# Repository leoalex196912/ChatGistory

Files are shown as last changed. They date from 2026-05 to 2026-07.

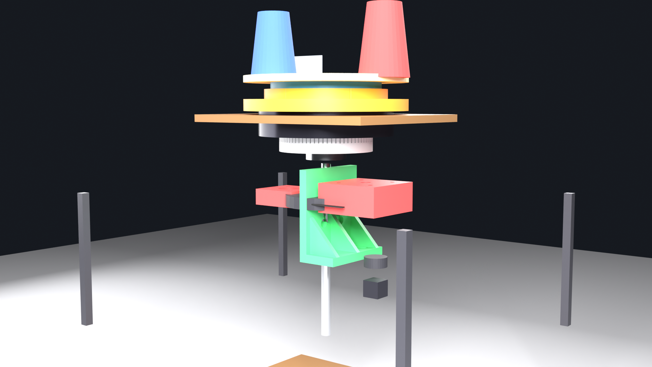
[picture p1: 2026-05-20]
3D-Project/00_PROJECT_OVERVIEW/renders/CSM_V3_Assembly_Hero.png

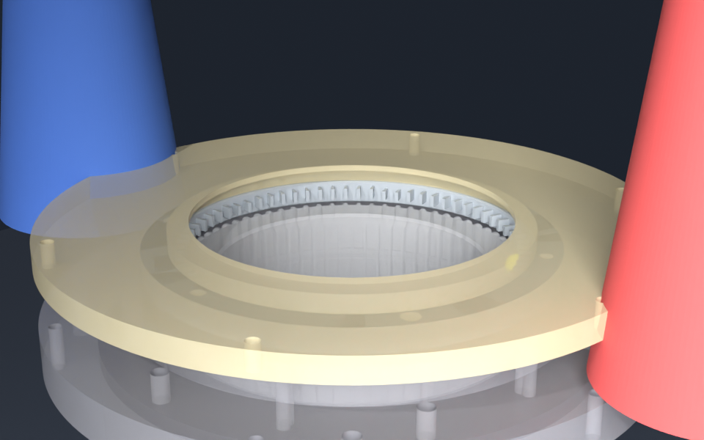
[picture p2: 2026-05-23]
CSM_V3_ASSEMBLY/full_assembly/renders/anim_nominal/frame_0004.png

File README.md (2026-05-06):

<<<<<<< HEAD
# CSM V3 - Computerized Sock Machine V3

Automated Legare-compatible circular sock knitting machine with motorized drive system and computer control.

## Project Status

| Component | Version | Status |
|---|---|---|
| Bearing Housings | V2.5.1 | ✅ Done |
| Drive Hub | V1.3 | ✅ Done |
| Motor Mount | V1.3 | ✅ Done |
| Spacer Tubes | V2.5.1 | ✅ Done |
| Cylinder | V1.1.1 | ✅ Done |
| Cam Ring | V6.5 FINAL | ✅ Done |
| Sinker Ring | V1.2.1 | ✅ Production-ready |
| Retainer Ring | V1.0 | NEXT |
| Cassette Base | V1.0 | After retainer |
| Feeder Module | V1.0 | After cassette |

## Latest: Sinker Ring V1.2.1

- 72 sinker projections with 10° backward angled tips
- Dual clearance test slices (ID 115.3mm and 115.1mm)
- 4 engineering review fixes applied
- ✅ Test slice printed successfully
- ✅ Angled tip geometry validated

## Directory Structure

- `chat-history/` - Full design conversation transcripts
- `freecad-macros/sinker-ring/` - FreeCAD macro (V1.2.1)
- `test-results/` - Print validation testing guide
- `documentation/` - Design specifications

## Next Steps

1. Validate test slice fit on cylinder
2. Print full sinker ring
3. Design Retainer Ring V1.0
4. Design Cassette Base V1.0

## Chat History

All design evolution documented chronologically in chat-history/.

See journal.txt for index.
=======
# ChatGistory
>>>>>>> 52dd906ae06a8ef9a5bce6f71aa1d95e0d1a725d

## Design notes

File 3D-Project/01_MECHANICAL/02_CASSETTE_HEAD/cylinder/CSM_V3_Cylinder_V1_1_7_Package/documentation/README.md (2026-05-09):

# CSM V3 Cylinder V1.1.7

## Status: PRODUCTION-READY (engineering review fixes applied)

## Project Location
`C:\3D-Project\01_MECHANICAL\02_CASSETTE_HEAD\cylinder\`

## Files In This Package

```
CSM_V3_Cylinder_V1_1_7_Package/
├── freecad_macros/
│   ├── CSM_V3_Cylinder_V1_1_7.FCMacro        (production - generates STL)
│   └── CSM_V3_Cylinder_V1_1_7_VIZ.FCMacro    (visualization with needles+spring)
├── blueprints/
│   └── Cylinder_V1_1_7_Blueprint.svg          (ready-to-view standalone SVG)
├── images/
│   (PNGs generated when you RUN the macro on Windows FreeCAD)
├── STL_outputs/
│   (STLs generated when you RUN the macro on Windows FreeCAD)
└── documentation/
    ├── README.md                              (this file)
    ├── VERSION_HISTORY.md
    └── CHAT_HISTORY_LATEST.txt
```

## Critical Specifications

| Parameter | Value | Notes |
|---|---|---|
| Cylinder OD | 114.3mm | Legare 4.5" standard |
| Cylinder ID | 88.0mm | Bore for drive hub |
| Height | 75.0mm | Total axial length |
| Slot count | 72 | Standard adult sock |
| Slot W × D | 1.22 × 2.00mm | For 12g needle ribbon |
| Slot length | 52.0mm | Stem zone |
| Slot chamfer | 0.8mm | Lead-in at top (V1.1.3 fix) |
| Butt cavity | 8.5 × 4.0mm | At Z=19-23mm (cam zone) |
| Spring groove Z | 60.4-63.6mm | Center Z=62mm (V1.1.7 fix) |
| Spring groove depth | 1.8mm | Less protrusion (V1.1.7 fix) |
| Hub pocket | 18.20mm × 3mm | Mates V1.3 drive hub |
| Bolts | 4× M5 @ PCD 70mm | Counterbored from below |
| Edge chamfer | 0.6mm | Top and bottom OD |

## Hardware Required

- **Cylinder spring**: FlyDesigns Common Thickness 0.110" / 2.79mm wire (purchased)
- **Needles**: 72× FlyDesigns AutoKnitter/Legare 12G (have 100)
- **Bolts**: 4× M5 socket head from screw kit
- **Loctite 603**: For bolt thread retention

## How To Use The Macros

### Step 1: Move files to project location
Copy these files to:
```
C:\3D-Project\01_MECHANICAL\02_CASSETTE_HEAD\cylinder\freecad_macros\
```

### Step 2: Run production macro
1. Open FreeCAD GUI (NOT freecadcmd headless)
2. Menu: Macro → Macros... 
3. Select `CSM_V3_Cylinder_V1_1_7.FCMacro`
4. Click Execute

This generates:
- `CSM_V3_Cylinder_V1_1_7_FULL.stl` (production cylinder)
- `CSM_V3_Cylinder_V1_1_7_TESTWEDGE.stl` (print first!)
- 4× PNG renders in `images/`
- 1× SVG blueprint in `blueprints/`

### Step 3: Run visualization macro (optional - to inspect with needles+spring)
Run `CSM_V3_Cylinder_V1_1_7_VIZ.FCMacro` to see the cylinder with 9 needles and the FlyDesigns spring rendered. Generates 5 additional PNG views including cross-section.

## Print Sequence (CRITICAL)

### Step 1: Print test wedge FIRST
- File: `CSM_V3_Cylinder_V1_1_7_TESTWEDGE.stl`
- Time: 30-45 minutes
- Material: ~10g PETG
- Settings:
  - Layer height: 0.20mm (or 0.16mm for higher precision)
  - Walls: 5
  - Top/bottom: 6 layers
  - Infill: 40% gyroid
  - Orientation: cylinder upright (axis Z)
  - Supports: NONE
  - Speed: ~40mm/s walls

### Step 2: Test fit
Insert a needle in each slot pair:
- Slots 1-2: 1.18mm (tightest)
- Slots 3-4: 1.20mm
- Slots 5-6: 1.22mm (TARGET)
- Slot 7: 1.24mm
- Slot 8: 1.26mm
- Slot 9: 1.28mm (loosest)

Each needle should:
- Slide smoothly up/down (no binding)
- Not rattle excessively (no slop)
- Spring back when flexed

Also verify:
- FlyDesigns spring fits in groove
- Spring wire centerline at Z=62mm
- Spring protrudes ~1mm past cyl OD

### Step 3: Print full cylinder
- File: `CSM_V3_Cylinder_V1_1_7_FULL.stl`
- Time: 4-6 hours
- Material: ~120g PETG
- Same settings as test wedge

If test wedge showed a different optimal slot width, edit `SLOT_WIDTH` in the macro and regenerate before printing full cylinder.

## Assembly Notes

1. Apply Loctite 603 to all 4 M5 bolts
2. Place cylinder onto V1.3 drive hub (boss enters pocket)
3. Insert M5 bolts through cylinder counterbores into hub
4. Tighten cross-pattern to ~5 Nm
5. Allow Loctite 603 to cure 24h
6. Install FlyDesigns spring:
   - Wrap around cylinder OD in spring groove (Z=60.4-63.6mm)
   - Twist ends together to close ring (per FlyDesigns instructions)
7. Insert needles from TOP of cylinder:
   - Lead-in chamfer guides needle
   - Push needle butt L into butt cavity
   - Spring should hold needle stem inward against back wall
8. Verify all 72 needles slide freely
9. Verify spring tension holds needles when cylinder tilted

## Validation

After assembly:
- [ ] Cylinder rotates smoothly on bearings (no binding)
- [ ] All 72 needles slide freely in slots
- [ ] Spring holds needles inward (no falling out when tilted)
- [ ] Hook clearance above cylinder top: ~2.5mm at rest
- [ ] Needle butts protrude past cylinder OD into cam ring path

## Version History

| Version | Date | Key Change |
|---|---|---|
| V1.0 | Apr 2026 | Initial 72-slot design |
| V1.1 | Apr 2026 | Added spring groove (initially at bottom - WRONG) |
| V1.1.1 | Apr 2026 | Refined spring groove dimensions |
| V1.1.2 | May 2026 | Added PNG export |
| V1.1.3 | May 2026 | Larger chamfer (0.4→0.8), groove relocation |
| V1.1.4 | May 2026 | Slot depth 1.90→2.00, batch boolean, wedge widths |
| V1.1.5 (viz) | May 2026 | Added spring visualization (still at bottom) |
| V1.1.6 | May 2026 | **Spring moved BOTTOM→TOP per Erlbacher reference** |
| **V1.1.7** | **May 2026** | **Z 68→62mm, depth 1.2→1.8, needle position fix** |

## Engineering Review Fixes In V1.1.7

**Fix #1**: Spring Z center 68mm → 62mm
- Better stem leverage (more lever arm)
- Material above groove: 5.4mm → 11.4mm (stronger top edge)

**Fix #2**: Spring groove depth 1.2mm → 1.8mm
- Spring protrusion: 1.59mm → 0.99mm
- Reduces yarn carrier snag risk

**Fix #3**: Needle radial position (visualization)
- Stems now positioned against back wall of slot
- Mechanically correct (spring naturally pushes needles inward)

## Z-Axis Layout (Final)

```
Z=75.0  ━━━━━━━━━━━━━ Cylinder TOP
        ━━ chamfer ━━
        |
        | 11.4mm solid material
        |
Z=63.6  ┃━━━━━━━━━━━┃ Spring groove TOP
Z=62.0  ┃    ●━━●    ┃ ← FlyDesigns 0.110" spring
Z=60.4  ┃━━━━━━━━━━━┃ Spring groove BOTTOM
        |
        | Stem zone (slot continues below)
        |
Z=23.0  ━━━━━━━━━━━━━ Slot bottom
Z=23.0  ┃   Butt    ┃ Butt cavity (8.5×4mm)
Z=19.0  ┃  cavity   ┃ (engaged by CAM ring)
        |
        | Solid base
        |
Z=0     ━━━━━━━━━━━━━ Cylinder BOTTOM (hub pocket)
```

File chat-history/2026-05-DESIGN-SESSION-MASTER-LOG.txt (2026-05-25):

================================================================
CSM V3 -- MASTER DESIGN-SESSION LOG  (2026-04-21 .. 2026-05-24)
================================================================

This document is the consolidated narrative of the most intensive
design-development phase of the CSM V3 project. It ties together
the five session-specific chat-history files (2026-05-19 through
2026-05-24) into one readable record, captures the back-and-forth
that the session files skipped, and serves as the canonical project
"design diary" for future-you (or anyone who picks this up cold).

If you want short answers, jump to the END (current status + open
items). If you want to understand HOW the project reached its
current architectural state, read top to bottom.

================================================================
TABLE OF CONTENTS
================================================================

1. Starting state (April 2026)
2. The architecture-document explosion (R1 -> R6)
3. The BOM reckoning (V11 -> V12)
4. The behavioral simulator (Phase 1.5)
5. The visual deliverables (renders + posters)
6. Cylinder V3.0 -> V3.1 from physical test
7. Repeated patterns and lessons
8. Status at end of session (2026-05-24)
9. Open items / next steps

================================================================
1. STARTING STATE (April 2026)
================================================================

The project entered May 2026 with:
- Locked Cylinder V3.0 (slot 1.22 wide x 3.0 deep, spring groove 1.3)
- Locked Cam Ring V6.5
- Locked Sinker Ring V1.2.1
- Locked Cassette Base V1.1
- Locked Retainer Ring V1.0
- Locked Drive Hub V2.4.2, Motor Mount V1.3, Bearing Housings V2.5
- BOM V11 (~$1,260 ordered, ~$1,468 final estimate)
- A confused "two-shelf table" frame architecture that the early
  Blender hero render exposed as visually wrong.

Architecture documents that existed:
- MACHINE_DATUMS.md R1 (basic constants)
- INTERFACE_CONTROL.md R1->R2 (9 interfaces locked)

What was missing:
- World coordinate system (only cylinder-local Z was defined)
- Three-layer architecture vocabulary
- Service envelope discipline
- Angular convention nailed down (theta=0 was implicit)
- Behavioral / kinematic model
- The drive-motor / feeder-motor identification was WRONG
  (docs assumed NEMA 17 + NEMA 11 -- BOM had NEMA 23 + MG90S)
- Frame architecture had floating ambiguity

================================================================
2. THE ARCHITECTURE-DOCUMENT EXPLOSION (R1 -> R6)
================================================================

Trigger: a comment that the early Blender hero render didn't match
the ChatGPT-generated machine poster. Investigation revealed that
the docs and the poster were both partially right and partially
wrong, and neither matched the actual BOM purchases.

Resolution: rewrite the architecture from the ground up.

Documents created or revised:

  (a) MACHINE_COORDINATE_SYSTEM.md  R1  (NEW)
      World frame (Z up, X motor side, Y operator).
      Cylinder-local frame (Z=0 at cylinder bottom).
      Locked transform: CYL_BOTTOM_WORLD_Z = 181 mm.
      Right-handed.

  (b) MACHINE_DATUMS.md             R1 -> R5
      R1 (2026-05-17): initial datums
      R2 (2026-05-20): added world-Z mapping, frame geometry, bought-parts
      R3 (2026-05-22): BOM ALIGNMENT -- discovered V11 had NEMA 23+gearbox
                       (not NEMA 17), MG90S servos (not NEMA 11 steppers),
                       S-250 PSU (not LRS-50), 60T+20T pulleys (not 60T+16T)
      R4 (2026-05-24): BELT GEOMETRY FIX -- motor moved from (90,-100) to
                       (85,-47) so center distance = 97.29 mm matches the
                       actual 405 mm belt geometry.  Separated 3 ratios:
                       gearbox 5:1, belt 3:1, total 15:1.
      R5 (2026-05-24): SLOT_DEPTH = 4.70, SPRING_GROOVE_DEPTH = 3.10
                       (locked from WEDGE_B V2 physical test).

  (c) INTERFACE_CONTROL.md          R1 -> R6
      R1-R2 (carryover): 9 interfaces locked from prior work
      R3 (2026-05-20): MAJOR REWRITE
          - NEW DO-NOT-BREAK invariants block (machine constitution)
          - NEW Sec 0: Three-Layer Architecture
                Layer 1 = Precision Knitting Core (cassette)
                Layer 2 = Structural Frame (wood + aluminum)
                Layer 3 = Automation (motors, electronics, mast)
          - NEW Sec 1: Datum Chain (master = aluminum plate top face)
          - NEW Sec 2: 5 Service Envelopes summary
          - Frame architecture totally re-spec'd
          - NEW Interface 10 (Touchscreen Mast - dual 2020, isolated)
          - NEW Interface 11 (Sock Take-Down Column - D100 reserved)
          - NEW Sec 4: Phase 1 / 1.5 / 2 / 3 upgrade path
      R4 (2026-05-22): BOM ALIGNMENT corrections to Interfaces 5 + 6
          - Interface 5: MG90S servos (NOT NEMA 11 steppers)
          - Interface 6: NEMA 23 + gearbox, 60T+20T+405mm belt
          - Motor Mount V1.3 flagged OBSOLETE -> V1.4 needed
      R5 (2026-05-22): Interface 12 (Shaft / Bearing Stack) added
          - Floating-top / fixed-bottom architecture formalized
          - Pulley sits BELOW lower bearing (not between)
          - DO / DON'T design rules
          - New invariant A8 (bearing stack)
          - R5 Design Rule: MG90S = "guided yarn presentation,"
            NOT precision synchronized actuation
      R6 (2026-05-24): Interface 11 ELEVATED
          - R6 Design Rule: "Take-down tension is a stitch-formation
            parameter, not a fabric-handling parameter."
            (Justified by Phase 1.5 B1 slack sensitivity = ±2 mm.)
          - Phase 2 architecture FORMALLY specified:
            dual-roller servo-controlled nip system
          - Phase 1 hanging weight reclassified as bring-up tool
          - Reason vacuum / conveyor / spring NOT chosen documented

  (d) SERVICE_ENVELOPES.md          R1  (NEW, 2026-05-20)
      SE1 = Cylinder removal (vertical lift)
      SE2 = Cam ring extraction (annular access from below)
      SE3 = Feeder swing-out (6 wedges at PCD 190)
      SE4 = Yarn threading (operator hand path)
      SE5 = Belt replacement (30 mm motor X-travel)
      Each envelope has 6 fields: purpose, protected volume,
        entry direction, tool access, prohibited geometry,
        future-risk notes.

  (e) ANGULAR_REFERENCE_STANDARD.md R1  (NEW, 2026-05-20)
      Locks the "theta=0 is NOT front" rule.
      theta=0 = +X = motor side = Hall index = Slot #0
      theta=90 = +Y = operator front
      Feeder positions F1-F6 numbered at 0/60/120/180/240/300 deg.
      Phase 1 ACTIVE = F1 (theta=0) + F4 (theta=180).
      F2/F3/F5/F6 = retainer-ring mount bolts (NOT empty).

  (f) machine_datums.py             (Python mirror)
      Self-checking module that mirrors MACHINE_DATUMS.md.
      Imports into every macro: NO hardcoded coords anywhere.
      Asserts derived CYL_BOTTOM_WORLD_Z matches the constant.

THE SIX DOCUMENTS NOW FORM A COHERENT GOVERNANCE STACK:
   MCS R1   - WHERE things are       (coordinates)
   MD R5    - WHAT things measure    (dimensions)
   ICD R6   - HOW things connect     (interfaces)
   SE R1    - HOW things are served  (maintenance envelopes)
   ARS R1   - HOW angles are named   (angular convention)
   machine_datums.py - machine-readable mirror of MD R5

================================================================
3. THE BOM RECKONING (V11 -> V12)
================================================================

The single most embarrassing moment in this session: the user had
to explicitly point me at the BOM file
("Why don't you read 04_PURCHASING/BOM_V11/CSM_V3_BOM_V11.html?")
because I had been making architectural decisions (motor = NEMA 17,
feeders = NEMA 11) based on conventional DIY-CSM assumptions rather
than the actual purchases.

What the BOM actually contained:
- NEMA 23 + 5:1 Planetary Gearbox (23HS22-2804S-HG5, $95
  StepperOnline)  -- NOT NEMA 17
- 60T + 20T + 405mm HTD belt kit (B0C6Y1462P)  -- NOT 60T + 16T
- 8x MG90S metal-gear servos for feeders  -- NOT NEMA 11 steppers
- S-250-24 PSU (199x98x38)  -- NOT LRS-50
- Raspberry Pi 4 4GB (NOT in my docs at all)
- All the small parts (heat-set inserts, T-nuts, magnets,
  hall sensors, springs, etc.)

After alignment:
- ICD R3 -> R4 incorporated correct motor/feeder/PSU
- machine_datums.py rewrote bought-parts section completely
- BOM V12 published (2026-05-24)

BOM V12 NEW items revealed by architecture lock:
  1. Wood Upper Deck 320x260x18 hardwood (~$15-25)
  2. M4 + M2 heat-set inserts (combined with existing 400-pc kit
     B0CLKDPN65, ~$18-25) -- includes M2/M2.5/M3/M4/M5/M6
  3. Take-down weight (CSM stem weight bag, Etsy, ~$15-25)
     -- Phase 1 BRING-UP TOOL ONLY (not production solution)
  4. Servo extension cables 10-pack (Cecicebb B0FXMDCP1H, $7.32)

BOM V12 ITEMS AUDITED-OUT (already owned, V11 covered them):
  - Yarn guide eyes: B0FLJK48BB ceramic pigtails (already in V11)
  - Tensioner springs: B0D1N3DKYJ springs set (already in V11)

Total V12 new spend: ~$56-82 (down from initial $65-95 estimate).
Final Phase 1 cost: ~$1,524-1,550.

VERIFY-ON-RECEIPT items:
  - Aluminum plate B0D9S2KH4V: confirm size = 250x250x6
  - HTD belt B0C6Y1462P: confirm width = 15 mm (vs 9 mm variant)

================================================================
4. THE BEHAVIORAL SIMULATOR (Phase 1.5)
================================================================

Conceptual evolution:

  Initial: "Phase 1.5 = animate the cylinder rotating in Blender"
  Refined: "Phase 1.5 = build the first BEHAVIORAL SIMULATOR"

Three tracks per simulation frame:
  (a) MECHANICAL STATE -- cylinder angle, needle Z, hook position
  (b) YARN STATE       -- endpoint, ownership, capture state
  (c) ERROR STATE      -- capture margin, phase, in-window flag

Deliverables built:

  D-1: Phase snapshots (nominal baseline)
       6 frames at theta = 0, 60, 120, 180, 240, 300 deg.
       Confirmed: hook peak at F1 and F4, smooth cosine bump.

  D-2: Failure mode taxonomy (8 scenarios, 4 classes)
       A. TIMING:    A1 feeder lag, A2 hook outrun, A3 belt jitter
       B. TENSION:   B1 slack loop, B2 over-tension
       C. GEOMETRIC: C1 retainer interference, C2 feeder intrusion
       D. CAPTURE:   D1 missed, D2 double-feed

  D-4 / D-4b: Parameter sweeps (21 runs, pure Python no Blender)
       A1 lag:    0, 2, 4, 6, 8, 10, 12, 15 deg
       B1 slack:  0, 2, 4, 6, 8, 12 mm
       D1 miss:   0, 2, 4, 6, 8, 12, 20 mm

  Output plots:
       capture_margin_plot.png     -- 3-panel overlay
       operating_envelope_plot.png -- worst-case vs parameter
       delta_from_nominal_plot.png -- Delta m(theta) by scenario

OPERATING ENVELOPES DERIVED FROM BEHAVIOR (acceptable at +-2 mm Z):

       A1  feeder lag           <= 10 deg     PHASE-sensitive
       B1  yarn slack           <=  2 mm      AMPLITUDE-sensitive
       D1  yarn miss / overlift =   0 mm      AMPLITUDE-sensitive (at edge!)

HIERARCHY OF FRAGILITY: D1 miss > B1 slack > A1 lag

KEY INSIGHTS THE SIMULATOR PROVED:

(a) Failure classification: phase-sensitive vs amplitude-sensitive
    Phase-asymmetric failures = timing problem (feeder lag,
       gearbox backlash, belt windup)
    Uniform offset failures = tension or geometry problem
       (take-down setup, retainer position)

(b) Take-down tension is a STITCH-FORMATION PARAMETER
    B1 slack at +-2 mm changes capture margin sign.
    Therefore take-down is coupled to capture stability,
    not downstream of it.
    -> ICD R6 elevated Interface 11 from "fabric handling"
       to "stitch formation subsystem"

(c) The cam stroke (8 mm) IS the safety budget for D1 miss
    Any yarn-presentation Z error eats directly into the
    HOOK_PEAK_Z (264) -> CYLINDER_TOP_Z (256) lift window.

================================================================
5. THE VISUAL DELIVERABLES (renders + posters)
================================================================

Progression through 3 distinct families:

  Family 1: Engineering renders (D1-D5)
       D1 = full isometric
       D2 = side elevation
       D3 = triad close-up
       D4 = top architecture plan
       D5 = layer separation exploded

  Family 2: Kinematic renders (K_triad_*, Y1-Y3)
       K_triad views = feeder/retainer/hook geometry
       Y1-Y3 yarn-path views = cone -> nozzle -> hook -> take-down

  Family 3: Phase 1.5 motion frames (36 nominal + 8 failure)
       36 frames covering one cylinder revolution
       8 failure-mode stills (one per scenario in taxonomy)

  Family 4: 6-poster engineering set (matplotlib composition)
       P1-P6 covering Architecture / Drivetrain / Yarn / Triad /
       Service / Failure-analysis

  Family 5: CANONICAL POSTER V2 (single ChatGPT-generated plate)
       Adopted as project visual reference 2026-05-24.
       2.2 MB. Lives at:
         CSM_V3_ASSEMBLY/full_assembly/renders/posters/
           CSM_V3_CANONICAL_POSTER_V2.png

Key visual-design lessons:

(a) First Blender render was BAD because half the scene used
    real STLs (cassette, drive train) and half used primitive
    boxes/cylinders (motor, frame, electronics). Mismatched
    fidelity hurts more than low fidelity uniformly applied.

(b) The "doesn't look good" was caused by:
    - Wrong frame proportions (table-on-table instead of single base)
    - Mast competing with cassette for visual attention
    - Cones loose on table (not on feeder modules)
    - Electronics hidden far below drive train
    All fixed in ICD R3 architecture rewrite.

(c) ChatGPT-generated marketing-style posters CAN match
    engineering CAD honesty IF the source data is locked
    architecture (which only became true after MD R4 + ICD R6).
    Before architecture lock, AI illustration = "concept art".
    After architecture lock, AI illustration = "engineering plate".

(d) Failure visualization is more informative than nominal-
    operation visualization. The 8 failure stills + the delta
    plot expose tolerance margins; the nominal renders only
    confirm geometry.

================================================================
6. CYLINDER V3.0 -> V3.1 FROM PHYSICAL TEST
================================================================

Test setup:
  - Printed WEDGE_B V2 (10-slot fine sweep 3.50..5.30 mm)
  - 12g FlyDesigns latch needles
  - Manual insertion + retention evaluation

Result:
  Slot 6 (4.50 mm depth, 2.90 mm groove)  -- tie / acceptable
  Slot 7 (4.70 mm depth, 3.10 mm groove)  -- BEST -- winner
  Slot 8 (4.90 mm depth, 3.30 mm groove)  -- loose -- past the edge

Lock (machine_datums.py + MACHINE_DATUMS R5):
  SLOT_DEPTH        = 4.70 mm  (was 3.00 in V3.0)
  SPRING_GROOVE_DEPTH = 3.10 mm  (was 1.30 in V3.0)
  Cylinder version V3.0 -> V3.1

Mechanical bonus discovered:
  V3.0 spring protruded 1.49 mm past cylinder OD --
    was eating into the 0.7 mm/side cam ring clearance.
  V3.1 spring is RECESSED 0.31 mm below OD --
    zero risk of cam ring interference.
  Better retention AND cleaner cam interaction.

This is the most important engineering result of the entire
session: the FINAL production cylinder geometry was derived
from PHYSICAL test data, not from intuition or first-principles
math. That is the correct engineering progression.

================================================================
7. REPEATED PATTERNS AND LESSONS
================================================================

(a) Architecture before geometry.
    Every time we tried to build geometry before locking the
    architecture (early Blender renders, V11 BOM motor decisions),
    rework followed. Every time we locked architecture first and
    let geometry follow (V3.1 cylinder, V12 BOM, Phase 1.5 sim),
    work compounded cleanly.

(b) BOM is the canonical reality.
    Architectural decisions made WITHOUT reading the BOM consistently
    diverged from physical reality. The discovery moment
    ("read the BOM!") was 2026-05-22; everything after that aligned.

(c) Behavior beats appearance.
    The 6-view canonical poster only earned its place after
    Phase 1.5 simulation results gave it real numerical grounding.
    Before that, posters were aesthetic interpretation.

(d) Documentation discipline scales.
    With 5 governance docs (MCS / MD / ICD / SE / ARS), changes
    can be made confidently because invariants are protected
    and revision history is auditable.

(e) Test-driven geometry.
    WEDGE_B physical test gave the cylinder its final lock.
    No amount of CAD precision substitutes for "push a needle
    into a printed slot and see what holds."

(f) Honesty about scope.
    Every "we'll add this in Phase 2/3" was logged explicitly.
    Includes: dual-roller take-down, ribber, vacuum assist,
    closed-loop tension, automatic heel/toe, multi-feed color
    changes, FeederModule V1.2 ceramic pigtail.

(g) Service envelopes are first-class objects.
    Most DIY machines fail not at assembly but at first service.
    SE1-SE5 prevent that by making maintenance access part of
    the geometry from day 1, not an afterthought.

================================================================
8. STATUS AT END OF SESSION (2026-05-24)
================================================================

ARCHITECTURE (locked):
  MACHINE_COORDINATE_SYSTEM.md  R1
  MACHINE_DATUMS.md             R5
  INTERFACE_CONTROL.md          R6
  SERVICE_ENVELOPES.md          R1
  ANGULAR_REFERENCE_STANDARD.md R1
  machine_datums.py             (R5-synced)
  CSM_V3_CANONICAL_POSTER_V2.png

LOCKED VERSIONS:
  Cylinder         V3.1  (slot 4.70 / groove 3.10) [2026-05-24]
  Cam Ring         V6.5
  Sinker Ring      V1.2.1
  Cassette Base    V1.1
  Retainer Ring    V1.0
  Drive Hub        V2.4.2
  Bearing Housings V2.5
  Motor Mount      V1.4  (NEMA 23 + HG5 bracket)
  Wood Base        V1.1  (D100 take-down hole)
  Wood Upper Deck  V1.0  (320 x 260 x 18)
  Mount Plate      V1.1  (250 x 250 x 6 master datum)
  Upright 2020     V1.1  (188 mm at corners of upper deck)
  Touchscreen Mast V1.0  (dual 2020 + crossbar)
  Feeder Module    V1.1  (MG90S cavity)
  NEMA17 STL       OBSOLETE -- replaced by NEMA23+HG5

BOM V12:
  - 4 items to order  (~$56-82 total)
  - Servo extension cables SKU locked: B0FXMDCP1H ($7.32)
  - Heat-set kit candidate: B0CLKDPN65 (Ktehloy 400-pc M2-M6)
  - Take-down weight candidate: Etsy CSM stem weight bag
  - Wood upper deck: Home Depot or local stock

PHASE 1.5 SIMULATOR:
  - 21 parameter sweep CSVs committed
  - 3 plots: capture margin, operating envelope, delta-from-nominal
  - Pure Python (no Blender) -- runs in seconds

VISUAL DELIVERABLES:
  - 6-poster engineering set (matplotlib)
  - Canonical poster V2 (ChatGPT-generated, adopted)
  - 36-frame nominal animation + metrics.csv
  - 8 failure scenario stills
  - Y1-Y3 yarn path renders
  - K_triad views
  - D1-D5 architectural views

================================================================
9. OPEN ITEMS / NEXT STEPS
================================================================

PHYSICAL (waiting on user):
  - Print Cylinder V3.1 FULL STL (~120g PETG, ~4-6 hr)
  - Order remaining 4 BOM V12 items
  - Verify aluminum plate size on receipt (250x250x6)
  - Verify HTD belt width on receipt (15 mm vs 9 mm)
  - Phase 1 bring-up assembly + first knit test with hanging weight

DOCUMENTATION (deferred, can be written any time):
  - F: DYNAMIC_BEHAVIOR_AND_COMPLIANCE.md
        Sections expected:
          - "Take-down tension is stitch-formation parameter"
          - Phase 1.5 D-4b tolerance results (A1<=10, B1<=2, D1=0)
          - Compliant-coupling Phase 2/3 investigation note
          - PETG creep / thermal / wear expectations
          - Service interval estimates
          - The "compliance > nominal dimensions" framing

DESIGN WORK (queued):
  - Phase 2 dual-roller take-down subsystem (~$60-110 hardware
    + FreeCAD design effort)
  - FeederModule V1.2 (replace printed yarn-exit hole with
    M3-threaded boss for ceramic pigtail from B0FLJK48BB)
  - 7-poster expansion adding Side Elevation + Top Plan
    (if v2 poster ever needs supplementing)

FUTURE PHASES (Phase 2/3 deferred):
  - 6-feeder active configuration (F2/F3/F5/F6 populated)
  - Ribber disk (Interface 8 provision exists)
  - Vacuum take-down (alternative to dual-roller)
  - Closed-loop tension control
  - Optical sock-length sensing
  - Automatic heel/toe shaping
  - Multi-feed color changes
  - Yarn mast for remote cone stand

KNOWN RISKS:
  - Slots 9-10 of WEDGE_B V2 (5.10/5.30 mm) were not tested due
    to print quality issues -- if user wants to push deeper, a
    V3 wedge would be needed
  - WEDGE_B V2 print didn't show 9/10 results, so the upper depth
    limit is established empirically at 4.90 mm (slot 8 loose)
  - PETG long-term creep under cam load not yet measured
    (will surface in Phase 1 bring-up)
  - HTD belt width 9 vs 15 mm could change motor mount slot
    specification (V1.4 -> V1.5 if 9 mm)

================================================================
END OF MASTER DESIGN-SESSION LOG
================================================================

This document captures the design evolution from
  early-May "concept render with wrong frame"
to
  end-May "production-locked architecture with simulator-derived
           tolerances and physical-test-locked cylinder geometry."

It is intended to be readable cold by a future-self or new
contributor. Cross-reference any specific decision against:
  - the per-session chat-history files
  - the document revision histories (each doc has its own log)
  - the git commit history (every change is traceable)

For the most recent canonical state, the source of truth is:
  3D-Project/00_PROJECT_OVERVIEW/
    MACHINE_COORDINATE_SYSTEM.md  R1
    MACHINE_DATUMS.md             R5
    INTERFACE_CONTROL.md          R6
    SERVICE_ENVELOPES.md          R1
    ANGULAR_REFERENCE_STANDARD.md R1
    machine_datums.py             (R5 mirror)

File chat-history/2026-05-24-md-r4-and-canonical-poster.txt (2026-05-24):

# CSM V3 -- Session Log 2026-05-24

## Summary

(A) MACHINE_DATUMS R3 -> R4 with belt-geometry correction
(B) CSM_V3_CANONICAL_POSTER_V2 adopted as canonical visual reference

================================================================
A. MACHINE_DATUMS R4 -- BELT GEOMETRY FIX
================================================================

ROOT CAUSE OF R3 BUG
--------------------
R3 had:
    MOTOR_X = 90.0,  MOTOR_Y = -100.0,  BELT_CENTER_DISTANCE = 134.5

That distance (sqrt(8100 + 10000) = 134.54 mm) is geometrically
impossible for the purchased belt:
    HTD 5M, 405 mm pitch length, 60T + 20T pulleys.

Belt-length equation:
    Lp = 2*C + pi*(D1+D2)/2 + (D1-D2)^2/(4*C)

With:
    D1 = 60*5/pi = 95.493 mm    (60T pitch diameter)
    D2 = 20*5/pi = 31.831 mm    (20T pitch diameter)
    Lp = 405 mm

Solving:
    8*C^2 - 4*k*C + (D1-D2)^2 = 0     where k = Lp - pi*(D1+D2)/2 = 205
    discriminant = k^2 - 2*(D1-D2)^2 = 33919.31
    C = (k + sqrt(disc)) / 4 = 97.293 mm    (real solution)
    C =  5.207 mm                            (degenerate, ignore)

So the only valid center distance is C = 97.29 mm.

R4 CORRECTIONS
--------------
- MOTOR_X = 85.0  (was 90.0)
- MOTOR_Y = -47.0 (was -100.0)
- New distance: sqrt(85^2 + 47^2) = 97.13 mm  (matches 97.29 within tension travel)
- NEW constant: BELT_CENTER_DISTANCE = 97.29
- Motor still in back-right quadrant (positive X = motor side,
  negative Y = back) -- preserves Interface 6 character

THREE DRIVETRAIN RATIOS now have named constants:
    GEAR_RATIO_GEARBOX = 5.0   (HG5 planetary)
    GEAR_RATIO_BELT    = 3.0   (60T : 20T)
    GEAR_RATIO_TOTAL   = 15.0  (5 * 3)
    Cylinder speed at 250 RPM motor input = 16.67 RPM

BELT_WIDTH = 15.00 mm flagged as TO-VERIFY
    BOM kit B0C6Y1462P ships either 9 mm or 15 mm width variants.
    Verify on physical receipt; update if 9 mm.

CHANGES TO FILES
----------------
- machine_datums.py: MOTOR_X / MOTOR_Y / BELT_CENTER_DISTANCE updated;
                     three named ratio constants; belt width note
- MACHINE_DATUMS.md: revision banner R3 -> R4; bought-parts section
                     updated with new motor position + belt geometry
                     derivation + ratio constants

================================================================
B. CANONICAL POSTER v2 ADOPTED
================================================================

FILE
    CSM_V3_ASSEMBLY/full_assembly/renders/posters/
        CSM_V3_CANONICAL_POSTER_V2.png   (2.2 MB)

SOURCE
    ChatGPT-generated unified 6-view engineering plate, 2026-05-24,
    after audit-driven corrections from the v1 release.

WHAT IT PASSES
--------------
All locked invariants represented correctly:
    Cylinder OD = 114.30 mm
    Hook Sweep OD = 113.30 mm (= 114.30 - 1.00 hook tip clearance)
    Retainer Lip ID = 104.00 mm
    Hook Peak Z (world) = 264 mm
    Retainer Lip Underside Z (world) = 270 mm
    Vertical Clearance = 6 mm  (highlighted in Panel 4 SAFETY BUDGET box)
    Reduction = 15:1  (5:1 gearbox * 3:1 belt)
    Cylinder Max RPM = 16.7 (at 250 RPM motor input)
    Needles / Slots = 72
    Feeder PCD = 190 mm
    Phase 1 = F1 (0 deg) + F4 (180 deg) ACTIVE; F2/F3/F5/F6 retainer-mount bolts
    Frame materials = wood + aluminum (no painted steel)
    Bearing stack = bottom fixed + 51101 thrust + top floating
    Coordinate system = +Z up, +X motor (0 deg), +Y operator (90 deg), CCW
    Stitch formation sequence shown (peak lift -> pull-down -> stitch -> release)
    All 6 panels present: Architecture / Drivetrain / Yarn / Triad / Service / Exploded

NON-BLOCKING CLEANUP ITEMS (for poster v3 later)
------------------------------------------------
1. Belt width: poster shows 9 mm; MD assumes 15 mm.
   Resolution: verify physical kit B0C6Y1462P on receipt, update whichever
   side is wrong.

2. Center distance: poster shows 110 mm; correct value is 97.29 mm
   (now in MD R4 -- poster v3 should regenerate from new MD).

3. Pulley Ratio label in Panel 2: incorrectly says "5:1 (Gearbox)"
   under "Pulley Ratio" -- should be:
       Pulley Ratio    60T : 20T = 3:1
       Gearbox Ratio   5:1
       Total           15:1

4. Layer classification in Panel 6: motor + gearbox listed under L2.
   Our ICD R5 §0 places them in L3 (Automation) and only motor-MOUNT
   bracket in L2. Either update poster to match ICD or update ICD to
   match poster (the poster's choice is defensible -- motor is
   structurally integrated with the frame).

5. "Interface 14 (Motor Mount)" in footer doesn't exist in ICD R5
   (we have I1-I12). Motor mount is part of Interface 6. Either remove
   line or relabel as "Part of Interface 6".

All 5 items are LABELING / CLASSIFICATION -- none affect machine physics.
Item 2 was the real engineering bug and is fixed in MD R4 above.

================================================================
ARCHITECTURE STATUS as of 2026-05-24
================================================================

Documents (canonical, in 3D-Project/00_PROJECT_OVERVIEW/):
    MACHINE_COORDINATE_SYSTEM.md  R1
    MACHINE_DATUMS.md             R4    (this update)
    INTERFACE_CONTROL.md          R5
    SERVICE_ENVELOPES.md          R1
    ANGULAR_REFERENCE_STANDARD.md R1
    machine_datums.py             (Python mirror, R4-synced)

Canonical visual reference:
    CSM_V3_ASSEMBLY/full_assembly/renders/posters/
        CSM_V3_CANONICAL_POSTER_V2.png

Machine identity (from poster summary):
    "CSM V3 is a compact 72-needle circular sock machine built around
     a protected kinematic core (Layer 1) suspended on a wood/aluminum
     structural frame (Layer 2) with isolated automation (Layer 3).
     The architecture prioritizes stitch quality, serviceability,
     and dynamic behavior within a benchtop footprint."

NEXT ACTIONABLE WORK
--------------------
- Receive belt kit -> verify belt width -> finalize BELT_WIDTH
- F: DYNAMIC_BEHAVIOR_AND_COMPLIANCE.md draft (data available from D-4b)
- Future poster v3 regeneration after MD R4 propagates
- BOM V12 with "still need to buy" list

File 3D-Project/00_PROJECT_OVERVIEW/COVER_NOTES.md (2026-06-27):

# CSM V3 — Project Cover & Overview Drawings

This folder contains two complementary architecture illustrations of the
complete CSM V3 machine.

## 1. `CSM_V3_MACHINE_COVER.png` — Canonical Project Cover

**Use this as the project's cover image** (READMEs, presentations, docs).

Professionally rendered isometric engineering illustration showing:

- Complete machine in 3/4 isometric view with all 14 modules labeled
- Cassette-stack close-up showing the retainer ring, 72-needle cylinder,
  spring groove, cam ring, sinker ring, cassette base
- "Cylinder — what it really looks like" section view + top view
- Machine dimensions (720 mm × 500 × 400)
- 14 Modules Overview index with color coding
- Yarn path & feeder layout (PCD 190, 6 feeders @ 60°)
- Key features panel
- Layer color key

### Dimensions shown on the cover

Most are direct from `machine_datums.py`. A few cylinder-internal
dimensions (butt cavity width 8.5 mm, butt cavity height 4 mm, "PCD 70")
are illustrative and may not be exact CAD values — verify against the
cylinder macro if you need them for manufacturing.

The slot length, spring groove position, cylinder OD/ID, and cassette
stack outer dimensions match `machine_datums.py` and the locked V3.1
specifications from physical test (WEDGE_B slot 7 winner: SLOT_DEPTH
= 4.70, SPRING_GROOVE_DEPTH = 3.10).

## 2. `CSM_V3_MACHINE_OVERVIEW_AUTO.png` / `.pdf` — Auto-Generated Diagram

Secondary, **data-driven** illustration auto-generated from
`machine_datums.py` via `generate_machine_overview.py`.

Use this when:

- You change `machine_datums.py` and want to verify the architecture
  visually
- You want a regenerable, lower-cost reference (no manual artwork
  required)
- You want a PDF/vector version for printable engineering reference

Both files are committed to GitHub as part of the project documentation.

## 14 modules listed on the cover

```
1.  Knitting Cylinder (V3.1, 72 slots)        Layer 1 — Precision
2.  Cam Ring (V6.5)                           Layer 1
3.  Sinker Ring (V1.2.1)                      Layer 1
4.  Cassette Base + Retainer + 6× Spacers     Layer 1
5.  6× Feeder Assembly (servo-driven)         Layer 1 / 3
6.  Drive System (NEMA 23 + HG5 5:1 + belt)   Layer 2
7.  Bearing & Shaft Stack                     Layer 2
8.  Take-Down (V1.0H hook / V2 dual-roller)   Layer 1
9.  Frame (wood base + 2020 + alu plate)      Layer 2
10. HMI (dual 2020 mast + 7" touchscreen + Pi 4)  Layer 3
11. Electronics (S-250-24 PSU + Mega + bucks + TB6600)  Layer 3
12. Operator Panel (E-stop + AC inlet + fuse)  Layer 3
13. Ribber Disk (provisioned for Phase 2)     Layer 1 (future)
14. Yarn Path (6 cones + ceramic pigtails)    Layer 1 / 5
```

## Architecture invariants (locked)

| Invariant | Value | Reference |
|---|---|---|
| Master datum (top of aluminum plate) | Z = 230 mm | ICD invariant B3 |
| Cylinder OD | 114.30 mm | machine_datums |
| Slot count | 72 @ 5° pitch | machine_datums |
| Slot depth | 4.70 mm | V3.1 locked from WEDGE_B |
| Spring groove depth | 3.10 mm | V3.1 locked |
| Cassette stack PCDs | 145 (cam pin), 155 (cam bolt), 180 (frame), 190 (feeder) | machine_datums |
| Master frame | 4× 2020 at (±150, ±120) × 188 mm | machine_datums (now 200 mm with 12 mm wood) |
| HMI mast | dual 2020 at (±75, -210) × 400 mm | ICD I10 / Module 10 |

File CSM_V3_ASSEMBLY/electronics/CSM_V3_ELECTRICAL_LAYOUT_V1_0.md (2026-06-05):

# CSM V3 — Electrical Physical Layout V1.0

**Status:** Day 1.5 companion to `CSM_V3_WIRING_V1_0.md`
**Created:** 2026-05-28
**Scope:** Two physical layouts — bench-test plywood (this week) and final wood-base mount
**Phase:** 1

> The wiring diagram (`CSM_V3_WIRING_V1_0.md`) defines what connects to what.
> This document defines **where each component physically lives**, its
> footprint, and how it bolts down. Use the bench-test layout for the
> 5–7 day wait window; switch to the final layout when ready to integrate.

---

## §0 Two layouts at a glance

| Layout | Substrate | Purpose | When |
|---|---|---|---|
| **Bench test** | ~600 × 400 mm plywood or cardboard | Validate electronics WITHOUT machine assembly | This week |
| **Final machine** | Wood Base V1.1 (500 × 400 × 18 mm hardwood) | Production mount | After bench test passes |

Component positions are different on each because:
- Bench test is laid out for **probing and debugging**: every wire reachable, every screw inspectable, generous spacing
- Final machine is laid out for **service and operation**: short cable runs, operator-reachable controls, no interference with cassette / motor / take-down

---

## §1 BENCH-TEST LAYOUT (this week)

### §1.1 Substrate

```
Plywood or cardboard, ~600 × 400 mm × 6 mm thick.
Any flat insulating sheet works. Pine, MDF, hardboard, cardboard, even foam board.
Do NOT use metal — risk of short-circuits.
```

Free hardware-store plywood scrap is ideal. Lay it on a workbench with corners overhanging so you can reach screws underneath.

### §1.2 Layout (top view, +X right, +Y back)

```
   Y=+400 ╔═══════════════════════════════════════════════════════╗
          ║                                                       ║
          ║   ┌───────────────────┐         ┌─────────────────┐   ║
          ║   │  S-250-24 PSU     │         │  Buck #1 (5V)   │   ║
          ║   │  199 x 110        │         │  Mega+servo rail │   ║
          ║   │  CHASSIS DOWN     │         └─────────────────┘   ║
          ║   │  vents UP         │         ┌─────────────────┐   ║
          ║   │                   │         │  Buck #2 (5V)   │   ║
          ║   │  terminals at +Y  │         │  Pi rail        │   ║
          ║   └─────────┬─────────┘         └─────────────────┘   ║
          ║             │                                          ║
          ║   AC pigtail ▼                       24 V bus terminal ║
          ║   to wall    │   ┌─────────────────┐  ┌──────────────┐ ║
          ║   ┌──────────┘   │  Arduino Mega   │  │ TB6600       │ ║
          ║   │              │  102 x 54       │  │ 96 x 56 x 37 │ ║
          ║   │ 2A T-fuse    │  on standoffs   │  │ (DIP set:    │ ║
          ║   │ E-stop NC    │                 │  │  8 microstep,│ ║
          ║   │              └────┬────────────┘  │  2.5 A)      │ ║
          ║   └────────┬──────────┘               └──────┬───────┘ ║
          ║            │ USB-B to laptop                 │ to NEMA ║
          ║            │ (Pi later)                      │ 23 wires║
          ║            │                                 │         ║
          ║            ▼ servo signals + servo extension rails     ║
          ║                                                        ║
          ║   ┌─────────────────────────────────────────────────┐  ║
          ║   │     Six MG90S servos (open frame, free pulleys) │  ║
          ║   │     Numbered 0..5, JST-XH leads to Mega         │  ║
          ║   └─────────────────────────────────────────────────┘  ║
          ║                                                        ║
   Y=0    ╚═══════════════════════════════════════════════════════╝
        X=0                                                    X=+600
```

### §1.3 Bench-test fasteners

Use **#6 wood screws** or **3M VHB tape squares**. Keep it removable:

| Component | Mount method on plywood |
|---|---|
| PSU | 4 × #6 wood screws through its M4 chassis holes (use M4-to-#6 washers) |
| Mega | 4 × M3 nylon standoffs to M3 self-tap into plywood |
| TB6600 | 2 × #6 screws through its flange mounting holes |
| LM2596 buck #1, #2 | 2 × #6 screws OR a 20×20 mm 3M VHB pad |
| Servos | Loose for the bench test; can be in any small box or zip-tied to plywood |
| AC pigtail | Strain-relief clamp at plywood edge, ~3 mm cable tie |
| Fuse holder | Panel-mount option: drill Ø12 mm hole and use the nut. In-line option: just leave the fuse in line, no panel mount. |
| E-stop | Hard-bolt to a small piece of scrap wood you can reach from the keyboard — 22 mm Ø mounting hole |

### §1.4 Bench-test wire-routing rules

- Keep mains side (AC entrance, E-stop, fuse, PSU L/N/PE) on **one corner** of the plywood, physically separated by at least 50 mm from low-voltage DC and signal wires
- Use a black sharpie to label every wire on both ends before connecting
- Run all DC wires along the X axis, all signal wires along the Y axis if possible — easier to trace at 2 AM
- One **kill switch on the wall outlet** in addition to the E-stop — until the E-stop is proven, pulling the wall plug is the real safety

---

## §2 FINAL MACHINE LAYOUT (Wood Base V1.1)

### §2.1 Wood base reference (from `machine_datums.py`)

```
WOOD_BASE_W = 500.0          (X dimension, "wide")
WOOD_BASE_D = 400.0          (Y dimension, "deep")
WOOD_BASE_T = 18.0           (Z thickness)
TAKEDOWN_HOLE_D = 100.0      at center (0, 0)
UPRIGHT_X_POSITIONS = (+150, -150)
UPRIGHT_Y_POSITIONS = (+120, -120)
MOTOR_X, MOTOR_Y = (+85, -47)    NEMA 23 mounts at gearbox side
```

### §2.2 Available real estate

The four perimeter strips outside the upright cage:

| Zone | X range | Y range | Width × Length | Available area |
|---|---|---|---|---|
| LEFT | −250 to −150 | −200 to +200 | 100 × 400 | 40 000 mm² |
| RIGHT | +150 to +250 | −200 to +200 | 100 × 400 | 40 000 mm² |
| FRONT | −150 to +150 | −200 to −120 | 300 × 80 | 24 000 mm² |
| BACK | −150 to +150 | +120 to +200 | 300 × 80 | 24 000 mm² |

Inside the upright cage is **reserved** for the cassette + motor + take-down column (do not place electronics there).

### §2.3 Component placement on wood base (top view)

```
   Y=+200 ╔══════════════════════════════════════════════════════╗
          ║                                                      ║
          ║  ┌──────┐     ┌─[BUCK #1]──[BUS]──[BUCK #2]─┐         ║
          ║  │      │     │   43x21    50x20    43x21   │   BACK  ║
          ║  │      │     │  (-50,+160) (0,+180)(+50,+160)│ strip ║
          ║  │      │     └──────────────────────────────┘        ║
   Y=+120 ║  │ PSU  │  ●──────────────────●                       ║
          ║  │      │                     │     ┌────────────┐    ║
          ║  │ 199  │                     │     │  Mega 2560 │    ║
          ║  │  x   │                     │     │  102 x 54  │    ║
          ║  │ 110  │     CAGE INTERIOR   │     │  (+200,+75)│    ║
          ║  │      │   (reserved for     │     └────────────┘    ║
          ║  │ at   │    motor + drive +  │                       ║
          ║  │(-195,│    take-down)       │     ┌────────────┐    ║
          ║  │  0)  │                     │     │  TB6600    │    ║
          ║  │      │     ○takedown       │     │  96 x 56   │    ║
          ║  │      │      Ø100           │     │(+200,-47)  │    ║
          ║  │      │                     │     │ (near motor)│   ║
          ║  │      │      ▦motor         │     └────────────┘    ║
   Y=−120 ║  └──────┘  ●──────────────────●                       ║
          ║                                                      ║
          ║  ┌──────────────────────────────────────────────┐    ║
          ║  │  FRONT OPERATOR PANEL (vertical, see §2.5)   │    ║
          ║  │  AC inlet | 2A fuse | E-stop | status LEDs   │    ║
          ║  └──────────────────────────────────────────────┘    ║
   Y=−200 ╚══════════════════════════════════════════════════════╝
        X=−250                                                X=+250
```

### §2.4 Component placements (precise coordinates)

#### PSU — S-250-24 (199 × 110 × 50 mm)

```
Center:           (X = −195, Y = 0)
Long axis:        along Y (so 199 mm long runs back-to-front)
Footprint X:      −250 to −140
Footprint Y:      −99.5 to +99.5
Height:           Z = 18 to Z = 68 (bottom on wood base top, vents up)
Terminal end:     at Y = +99.5 (facing BACK strip — keeps wires away from operator)
Chassis screws:   4 × M4 through its bottom mounting holes
                  Hole pattern per Mean Well datasheet (typical 188 × 90 inner spread)
Fastener into wood: M4 × 25 mm wood screw OR M4 × 30 with washer + nut from underside
```

> ⚠ The PSU body extends to X = −140, which is **10 mm past the upright line at X = −150**. The uprights are 20×20 posts at (−150, ±120) — their Y is ±120, outside PSU Y range (−100 to +100). PSU clears them laterally with ~20 mm gap.

#### TB6600 stepper driver (96 × 56 × 37 mm)

```
Center:           (X = +200, Y = −47)
Footprint X:      +152 to +248
Footprint Y:      −75 to −19
Mount:            2 × M3 × 16 mm wood screws through driver flange tabs
Wires to motor:   short run (~50 mm) to NEMA 23 at (+85, −47)
Cable management: zip-tie ferrule the motor wires at the wood base edge
```

#### Arduino Mega 2560 (102 × 54 mm board)

```
Center:           (X = +200, Y = +75)
Footprint X:      +149 to +251 (slightly overhangs wood edge — OK, USB end faces out)
Footprint Y:      +48 to +102
Mount:            4 × M3 × 10 mm nylon standoffs to M3 self-tap into wood
Standoff height:  10 mm (airflow under PCB, prevents wood-moisture absorption)
USB-B port:       faces +X (off-base side) for easy programming access
```

#### LM2596 bucks × 2 (43 × 21 mm each)

```
Buck #1 (Mega+servos):
  Center:         (X = −50, Y = +160)
  Footprint X:    −71.5 to −28.5
  Footprint Y:    +149.5 to +170.5
  Mount:          2 × M3 × 8 mm standoffs OR a 20×20 mm 3M VHB pad
  
Buck #2 (Pi):
  Center:         (X = +50, Y = +160)
  Footprint X:    +28.5 to +71.5
  Footprint Y:    +149.5 to +170.5
  Mount:          Same as Buck #1
  
Spacing rule:    Keep the two bucks ≥ 50 mm apart so the LM2596 inductors don't
                 magnetically couple under load.
```

#### 24 V distribution terminal block (WAGO 221-415 or similar, ~50 × 20 mm)

```
Center:           (X = 0, Y = +180)
Mount:            DIN-rail clip OR 2 × M3 wood screws to the base directly
Function:         Bus tap point — PSU +V / −V trunk lands here, branches fan
                  out to TB6600, Buck #1, Buck #2, future accessory
Wire labels:      "+24V BUS" / "0V BUS" with shrink-tube labels at each leg
```

### §2.5 Front operator panel (vertical sub-assembly)

A small vertical panel L-bracketed to the front edge of the wood base. Operator interface lives here.

```
Panel dimensions: 200 × 60 × 3 mm
Material:         3 mm plywood OR 2 mm aluminum (aluminum preferred for EMI shielding)
Position:         centered at X = 0, mounted on the Y = −200 edge
Top of panel:     Z = 18 + 60 = 78  (just below wood-upper-deck level)
Mount:            2 × small L-brackets (15 × 15 mm) on rear face of panel, M4 wood
                  screws into the wood base front edge

Cutouts (front face, left to right):
┌─────────────────────────────────────────────────────┐
│                                                     │
│  IEC C14 inlet      Fuse holder      E-STOP         │
│  cutout 27 × 19     Ø12 mm           Ø22 mm         │
│  at X = −70         at X = −25       at X = +20     │
│                                                     │
│                                       ● ● POWER     │
│                                       ● ● FAULT     │
│                                       LEDs Ø5 mm    │
│                                       at X = +75    │
└─────────────────────────────────────────────────────┘
       60 mm tall × 200 mm wide

Cable entries:    Through the wood base side (back face of operator panel)
                  Bring AC mains in at IEC inlet, route inside the cage to PSU
                  E-stop NC contacts wire back into mains-side circuit
                  LED wires come from Mega digital pins via current-limiting Rs
```

### §2.6 Cable routing rules on the wood base

1. **Mains AC** runs in the FRONT zone only, between the operator panel and the PSU AC terminals. Keep it on the −Y side of any DC wires.
2. **24 V DC** runs in the BACK zone from PSU terminals to the distribution block, then branches out.
3. **5 V** rails run on the BACK and RIGHT strips: Buck #1 → Mega and feeder servo extensions; Buck #2 → Pi (if on-machine).
4. **Signal wires** (PWM, UART, step/dir/en) run along the RIGHT strip.
5. **Crossing AC and DC**: only at right angles, with at least 50 mm vertical separation (mains side close to wood, DC slightly elevated, or vice-versa)
6. **Cable strain relief**: use Heyco bushings or rubber grommets at every cable that enters or exits the wood base perimeter
7. **Earth bonding** wire (PSU FG → frame if metal): runs back-to-front along the wood base centerline

### §2.7 Mounting hardware bill of materials for the final layout

| Item | Qty | Use |
|---|---|---|
| M4 × 25 mm wood screw | 4 | PSU chassis |
| M4 washer | 4 | Under PSU screw heads |
| M3 × 16 mm wood screw | 2 | TB6600 flange |
| M3 × 10 mm nylon standoff | 4 | Mega |
| M3 × 6 mm screw | 8 | Mega standoff top + bottom |
| M3 × 8 mm standoff | 4 | Bucks (or 4× VHB pads) |
| M3 × 12 mm wood screw | 2 | DIN-rail clip or terminal block |
| L-bracket 15 × 15 mm | 2 | Front operator panel |
| M4 × 10 mm wood screw | 2 | L-bracket to wood base |
| M3 × 8 mm screw | 2 | L-bracket to panel |
| Rubber grommet Ø8 mm | 4 | Cable entry strain reliefs |
| Cable ties 100 mm | 20 | Cable routing |
| Ferrule kit (0.5 – 2.5 mm²) | 1 | Every conductor into a screw terminal |

---

## §3 Cross-references

- `CSM_V3_WIRING_V1_0.md` — electrical schematic, fuse values, wire colors
- `INTERFACE_CONTROL.md` (R6) — frame architecture, Interface 6 (cassette to frame) and Interface 10 (touchscreen mast)
- `machine_datums.py` — single source for all wood-base + upright coordinates
- `CSM_V3_WoodBase_V1_1.FCMacro` — current wood-base STL (already includes the D100 take-down hole; does NOT yet include electronics mounting holes)

---

## §4 What's still TBD

These need real-world decisions or measurements:

- [ ] PSU chassis-screw hole pattern (Mean Well datasheet figure — verify with calipers when unit is in hand)
- [ ] TB6600 flange-hole pitch (verify on actual unit)
- [ ] Whether Raspberry Pi 4 goes on touchscreen mast (recommended) OR also on wood base — Pi+touchscreen sub-assembly design is a separate document
- [ ] E-stop button model (BOM still doesn't show one ordered — pick a 22 mm panel mount, NC+NC double-pole, 10A/250V rated)
- [ ] IEC C14 inlet model and exact cutout dimensions (depends on chosen part)
- [ ] Wood-base electronics-mounting holes (drilled in V1.2 wood base, not V1.1 — V1.1 doesn't have them; mark and drill once layout is finalized)

---

## §5 Revision log

| Rev | Date | Author | Change |
|---|---|---|---|
| V1.0 | 2026-05-28 | claude | Initial layout — bench test + final wood base + operator panel |

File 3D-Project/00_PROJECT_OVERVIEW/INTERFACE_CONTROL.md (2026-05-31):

# INTERFACE_CONTROL.md — CSM V3 Interface Control Document (ICD)

```
Revision:  R6
Date:      2026-05-24
Status:    Active — locked interfaces, change requires version bump on
           BOTH mating parts AND an ICD revision bump.
           R6 elevates Interface 11 (Take-Down Column) to "stitch-
           formation parameter" status -- Phase 1.5 D-4b proved
           take-down tension is coupled to capture stability, not
           independent of it. Also formalizes the Phase-2 automated
           take-down architecture (dual-roller servo nip system) and
           explicitly classifies the Phase-1 hanging weight as a
           bring-up / debug / calibration tool, not a production
           solution.
```

This is the **interface control document** for the CSM V3 modular
machine. It captures every mating relationship between components,
every reserved volume, and every architectural invariant that any
future change must respect.

The architecture is **frame-locked, polymer-flexible**: material
selection per component may evolve from PETG → PA12 → 6061, but the
interfaces defined here must not.

---

## ⚠ DO-NOT-BREAK INVARIANTS — MACHINE CONSTITUTION

```
═══════════════════════════════════════════════════════════════════════
LOCKED ARCHITECTURE INVARIANTS  —  BREAKING CHANGE WARNING
═══════════════════════════════════════════════════════════════════════
Modifying ANY of the following requires:
  - bumping this ICD revision (R3 → R4)
  - bumping the version of every dependent component macro
  - re-validating all 5 service envelopes
  - written justification in the ICD revision history
  - sign-off in chat-history before commit

A. DIMENSIONAL INVARIANTS
   A1.  Cylinder OD                = 114.30 mm  (Legare 4.5" standard)
   A2.  Cam Ring ID                = 115.00 mm  (0.35 mm/side clearance)
   A3.  Cam ring bolt PCD          = 155.0  mm  (6× M5, 30° offset)
   A4.  Cam ring dowel PCD         = 145.0  mm  (6× D4, alternating)
   A5.  Cassette feeder PCD        = 190.0  mm  (6× M4, 60° — shared by
                                                 feeders AND retainer)
   A6.  Cassette frame-mount PCD   = 180.0  mm  (4× M5, 45° offset)
   A7.  CYL_BOTTOM_WORLD_Z         = 181.0  mm  (world↔local transform)
   A8.  Shaft bearing stack        = floating-top, fixed-bottom
                                     (Interface 12) -- lower thrust
                                     bearing resolves axial load;
                                     upper bearing free for thermal growth

B. GEOMETRIC / DATUM INVARIANTS
   B1.  Cylinder-local Z origin    = cylinder bottom face
                                     (where it sits on drive hub boss)
   B2.  CAM_DATUM_Z = 49           = cassette base bottom mating plane
                                     (cylinder-local)
   B3.  Aluminum plate top face    = WORLD MASTER DATUM (Z = 230 mm)
                                     — precision reference for cassette,
                                     drive shaft, and bearing alignment
   B4.  θ = 0°  alignment          = cylinder slot #0 ∥ +X axis
                                     = Hall sensor magnet at θ = 0°
                                     = motor side
   B5.  Coordinate handedness      = right-handed
                                     (+X motor, +Y operator, +Z up)

C. PHILOSOPHICAL / ARCHITECTURAL INVARIANTS
   C1.  Cassette = removable knitting head, mounts as ONE unit to
        the aluminum master-datum plate.
   C2.  Sock take-down column (cylinder axis, world X = Y = 0,
        from drive hub bore exit DOWNWARD through D100 hole in
        wood base) MUST remain unobstructed by motors, electronics,
        cables, or structural members.
   C3.  Service envelopes SE1–SE5 are protected volumes — no fixed
        geometry may occupy them (see §2 and SERVICE_ENVELOPES.md).
   C4.  Three-layer subsystem separation (Precision / Structural /
        Automation) is the design organizing principle. Components
        belong to exactly one layer.

Everything else in this document is revisable through normal
version-bump workflow without an ICD revision bump.
═══════════════════════════════════════════════════════════════════════
```

---

## §0  Three-Layer Architecture

CSM V3 is organized into three subsystems with different iteration
rates and tolerance requirements:

```
┌─ Layer 1: PRECISION KNITTING CORE  ────────────────────────────┐
│  Cylinder · Cam Ring · Sinker Ring · Retainer Ring ·           │
│  Cassette Base · (future) Ribber                                │
│  Iteration: SLOW. Tolerances: tight. Mounts as one removable    │
│  cassette to the master datum plate.                            │
└─────────────────────────────────────────────────────────────────┘
┌─ Layer 2: STRUCTURAL MACHINE FRAME  ───────────────────────────┐
│  Wood base · 4× 2020 uprights · Wood upper deck · Aluminum     │
│  master-datum plate · Drive hub · Bearing housings ·           │
│  12 mm shaft · Motor mount                                      │
│  Iteration: MEDIUM. Vibration isolation between Layer 3 sources │
│  and Layer 1 precision zone.                                    │
└─────────────────────────────────────────────────────────────────┘
┌─ Layer 3: AUTOMATION / CONTROL  ───────────────────────────────┐
│  NEMA 17 drive motor · HTD pulleys + belt · Feeder modules     │
│  (with NEMA 11 motors) · Electronics enclosure (Mega, TB6600,  │
│  LRS-50) · Touchscreen 7" + dual-upright mast · Yarn mast      │
│  Iteration: FAST. Mechanically isolated from Layer 1.           │
│  Touchscreen mast does NOT touch the precision frame.           │
└─────────────────────────────────────────────────────────────────┘
```

Layer assignment determines where a component is documented, what
its version bump cadence looks like, and which interfaces it can
modify. A component cannot belong to two layers.

---

## §1  Datum Chain

The single alignment chain that governs the whole machine:

```
ALUMINUM PLATE TOP FACE  (world Z = 230, master datum)
        │
        ├── Cassette Base bottom (cylinder-local Z = 49)
        │     ├── Cam Ring top (registered by PCD 155 bolts + PCD 145 pins)
        │     │     └── Cylinder OD (concentric clearance fit, 115.0/114.3)
        │     │           └── Drive Hub boss (PCD 70 bolt circle into
        │     │                                cylinder bottom inserts)
        │     │                 └── 12 mm drive shaft
        │     │                       └── Bearing housing alignment
        │     │                             └── (orthogonal to aluminum
        │     │                                  plate top normal vector)
        │     ├── Sinker register pocket (D135.30)
        │     │     └── Sinker Ring OD 135 (slip fit)
        │     └── Feeder PCD 190 + Retainer PCD 190 (shared)
        │           ├── Feeder Modules (Phase 1: 2 of 6 positions)
        │           └── Retainer Ring (uses remaining 4 positions)
        │
        └── Frame mount PCD 180 (4× M5) into aluminum plate
              └── Aluminum plate is itself bolted to wood upper deck
                    └── Wood upper deck rests on 4× 2020 uprights
                          └── Uprights bolt into wood base (Z = 18)
                                └── Wood base on rubber feet (Z = 0)
```

**Alignment rule:** the aluminum plate top face is the only true
precision plane. Wood layers below provide damping and stiffness, but
their flatness is not part of the precision chain. Cassette alignment
is set against the plate, then locked.

---

## §2  Service Envelopes (summary)

Five reserved volumes ensure the machine is serviceable in production,
not just buildable on a bench. Full definitions in
`SERVICE_ENVELOPES.md`. No fixed geometry may occupy these volumes.

| ID | Name | Purpose | Volume summary |
|---|---|---|---|
| **SE1** | Cylinder removal | Lift cylinder vertically out of cassette without disassembling cam ring or feeders | Column on cylinder axis, world Z = 272 (retainer top) up to Z ≥ 395; radius ≥ cylinder OD/2 + 5 mm |
| **SE2** | Cam ring extraction | Un-bolt cam ring from cassette base bottom and drop it off | Radial ring at world Z 212–230, D165 → D200, accessed from below |
| **SE3** | Feeder swing-out | Remove a feeder module via 2× M4 + radial slide | Per-position clearance: 60 mm radial outside PCD 190 + tool access from above at PCD 190 |
| **SE4** | Yarn threading | Operator can see + thread yarn from feeder exit to needle hook from front (+Y) | Horizontal arc at world Z 264–280, front half of cassette (Y > 0); no upright in operator hand path |
| **SE5** | Belt replacement | Slacken belt by sliding motor toward drive shaft, remove belt over pulley | Motor X-travel slot: 30 mm toward drive shaft; vertical clearance ≥ 80 mm above pulleys |

The take-down column (invariant C2) is a sixth protected volume but
conceptually a SYSTEM, not just a service envelope — see Interface 11.

---

## §3  Interfaces

Convention: **PCD** = Pitch Circle Diameter (mm). All linear units mm,
all angular units degrees.

### Interface 1: Drive Hub ↔ Cylinder

| Property | Value | Locked by |
|---|---|---|
| Mating method | Boss into pocket + bolt circle | both V2.4.2 + V3.0 |
| Concentric registration | D18.0 boss → D18.2 pocket (0.20 mm slip fit) | Drive Hub V2.4.2 |
| Bolt PCD | 70.0 | both |
| Bolt count | 4× M5 | both |
| Bolt angular offset | 45° (45/135/225/315) | both |
| Hardware | M5 brass heat-set inserts in cylinder (B0DPQJ4W3Z) | BOM_V11 |
| Bolt direction | Up from below drive hub flange, through countersinks, threaded into cylinder inserts | Drive Hub V2.4.2 |

### Interface 2: Cylinder ↔ Cam Ring

| Property | Value | Locked by |
|---|---|---|
| Mating method | Rotational concentric clearance (cylinder rotates inside stationary cam) | both V3.0 + V6.5 |
| Cylinder OD | 114.30 (invariant A1) | Cylinder V3.0 |
| Cam Ring ID | 115.00 (invariant A2) | Cam Ring V6.5 |
| Radial clearance | 0.35 mm/side | derived |
| Cam track Z range | Z=19 to Z=31 (cylinder local), engages butts | Cam Ring V6.5 + cylinder slot geometry |
| Cam lift | 8 mm (smoothstep cubic) → HOOK_PEAK_Z = 83 | Cam Ring V6.5 |
| Butt zone | within cylinder slot opening (Z = 12-75) | Cylinder V3.0 |

### Interface 3: Cam Ring ↔ Cassette Base

| Property | Value | Locked by |
|---|---|---|
| Mating method | Cam ring bolts UP from below into cassette base | both V6.5 + V1.1 |
| Bolt PCD | 155.0 (invariant A3) | both |
| Bolt count | 6× M5 | both |
| Bolt angular offset | 30° (30/90/150/210/270/330) | both |
| Pin PCD | 145.0 (invariant A4) | both |
| Pin count | 6× D4 dowels | both |
| Pin angular offset | 0° (0/60/120/180/240/300, alternating with bolts) | both |
| Cam ring top Z | 49.0 (= CAM_DATUM_Z, invariant B2) | both |

### Interface 4: Cassette Base ↔ Sinker Ring

| Property | Value | Locked by |
|---|---|---|
| Mating method | Sinker drops into register pocket on pedestal top | both V1.1 + V1.2.1 |
| Pedestal OD | 150.0 | Cassette Base V1.1 |
| Pedestal ID | 128.0 (annular) | Cassette Base V1.1 |
| Pedestal height | 12.0 (= SINKER_Z − CASSETTE_TOP_Z) | Cassette Base V1.1 |
| Register pocket diameter | 135.30 | Cassette Base V1.1 |
| Register pocket depth | 1.0 mm | Cassette Base V1.1 |
| Sinker Ring OD | 135.00 | Sinker Ring V1.2.1 |
| Slip fit clearance | 0.15 mm/side | derived |
| Sinker register plane (top of pocket) | Z = 75 (= SINKER_Z, cylinder-local) = 256 world | both |

### Interface 5: Cassette Base ↔ Feeder Modules  *(R4 update — actuator change)*

| Property | Value | Locked by |
|---|---|---|
| Bolt PCD | 190.0 (invariant A5) | Cassette Base V1.1 |
| Bolt count | 6× M4 | Cassette Base V1.1 |
| Bolt angular offset | 0° (0/60/120/180/240/300) | Cassette Base V1.1 |
| Hardware | M4 brass heat-set inserts in cassette base | per material — PETG/PA12 supports inserts |
| Phase 1 active feeders | 2 (positions F1 θ=0° and F4 θ=180°) | architecture decision (ANGULAR_REFERENCE_STANDARD) |
| Retainer Ring mount | Shares same 6 bolt pattern (positions 60/120/240/300 unused by feeders) | Interface 7 |
| **Feeder actuator (Phase 1)** | **MG90S metal-gear servo (22.8×12.2×28.5 body, 32 mm tab-to-tab)** | R4 — matches BOM V11 (8× purchased: 6 active + 2 spare). REPLACES the R3 NEMA 11 spec. |
| Servo control signal | PWM 50 Hz, 1.0–2.0 ms pulse, 180° rotation | MG90S spec |
| Servo power | 6 V (via LM2596 buck from 24 V S-250 PSU) | BOM B008BHB4L8 |
| Feeder yarn exit Z (world) | 271 (= FEEDER_REFERENCE_Z + CYL_BOTTOM_WORLD_Z = 90 + 181) | provisional; validated in Phase 1.5 |
| Feeder yarn exit radius | 95 mm (approx, at PCD 190 / 2) | Feeder Module V1.0 spec |
| Service envelope | SE3 reserved per feeder position | SERVICE_ENVELOPES.md |

**R4 Note:** The feeder module 3D-printed enclosure (currently
`FeederModule V1.0` with a 28×32 mm motor cavity) needs **V1.1** to
fit the MG90S servo (smaller cavity 23×13 mm with 2× M2 mounting
tabs at 28 mm pitch). Cavity and bolt-pattern change only — the
external footprint and PCD 190 mount geometry unchanged.

**R5 Design Rule — Feeder Control Philosophy:**
MG90S servos introduce backlash, positional uncertainty, PWM timing
jitter, and gear wear. Phase 1 feeder logic must treat servos as
**"guided yarn presentation,"** not as "precision synchronized
textile actuation." Specifically:
- ✅ ACCEPTABLE: yarn guide positioning, tension modulation, simple
  swing-in / swing-out of feeder fingers, color-change selection.
- ❌ NOT ACCEPTABLE in Phase 1: needle-by-needle synchronized
  selection (per-stitch jacquard), high-frequency yarn cutting,
  precision-timed yarn injection mid-stitch.
- Phase 2 may upgrade to NEMA-class steppers for selected feeders
  if precision selection becomes a requirement. Bolt pattern at
  PCD 190 is unchanged, so the swap is per-feeder without
  architectural impact.

### Interface 6: Cassette Base ↔ Frame + Drive Motor  *(R4 update — motor change)*

The frame is **completely re-architected** from R2. There is no longer
a "wood mid-shelf" the size of the wood base. Instead, a compact upper
deck holds the precision cassette, with all dimensions measured from
the cylinder axis (FRAME_ORIGIN_XY = (0, 0)).

| Property | Value | Locked by |
|---|---|---|
| Cassette mount bolt PCD | 180.0 (invariant A6) | Cassette Base V1.1 |
| Bolt count | 4× M5 | Cassette Base V1.1 |
| Bolt angular offset | 45° (45/135/225/315) | Cassette Base V1.1 |
| Aluminum plate (master datum) | 250 × 250 × 6 mm, 6061-T6 mill finish | R3 — replaces R2 150×150 |
| Aluminum plate top Z | 230 world (invariant B3) | R3 |
| Wood upper deck | 320 × 260 × 18 mm hardwood | R3 NEW |
| Wood upper deck top Z | 224 world | R3 |
| 2020 uprights | 4 ×, 188 mm length, at world (±150, ±120) | R3 NEW positions |
| Upright top Z | 206 world | R3 |
| Wood base | 500 × 400 × 18 mm hardwood, with D100 center take-down hole | R3 (hole NEW) |
| Wood base top Z | 18 world | R3 |
| Hardware | M5 with T-nuts in 2020 channel + M5 through wood upper deck into aluminum plate inserts | BOM_V11 |
| **Drive motor** | **NEMA 23 + 5:1 planetary gearbox (23HS22-2804S-HG5)** | R4 — replaces R3 NEMA 17 |
| Drive motor body | 57×57×56 mm + 50 mm gearbox = 106 mm total length | NEMA 23 + HG5 spec |
| Drive motor mount | 4× M5 at PCD square 47.14 mm | NEMA 23 frame |
| Drive motor position | World (X=+90, Y=−100, Z_bot=18) | MD.MOTOR_X/Y/Z |
| Drive belt | HTD 5M, 405 mm pitch length, 15 mm wide (kit B0C6Y1462P) | BOM_V11 |
| Drive pulleys | 60T (gearbox, 14 mm bore) + 20T (drive shaft, 12 mm bore) | BOM_V11 |
| Total reduction | 5 × 3 = **15:1** motor → cylinder | gearbox + belt |

**R4 Note:** `Motor Mount V1.3` was designed for NEMA 17 geometry
(M3 mount PCD 31). NEMA 23 has M5 mount PCD 47.14. **Motor Mount
needs V1.4** to accommodate the larger NEMA 23 + gearbox stack.
Existing Motor Mount V1.3 STL is now obsolete for the drive train
(may be reusable for other purposes).

### Interface 7: Cassette Base + Sinker Ring ↔ Retainer Ring  *(unchanged from R2)*

| Property | Value | Locked by |
|---|---|---|
| Mating method | Retainer sits ABOVE sinker, mounts to cassette base via shared feeder bolts at PCD 190 | both V1.1 + V1.0 |
| Retainer Ring OD | 200.0 | Retainer Ring V1.0 |
| Retainer Ring through-bore | D118.0 | Retainer Ring V1.0 |
| Loop-control lip diameter | D104.0 effective loop aperture | Retainer Ring V1.0 |
| Lip height (from top of ring) | 2.0 mm (top portion only, ring is 8 mm total) | Retainer Ring V1.0 |
| Retainer assembly Z (bottom face, cylinder-local) | 83 = HOOK_PEAK_Z = world 264 | architecture |
| Lip underside world Z | 270 | derived |
| Hook clearance under lip | 6 mm (lip at 270-272 vs HOOK_PEAK_WORLD_Z = 264) | derived |
| Mount bolt PCD | 190.0 (SAME as cassette feeder PCD — invariant A5) | both V1.1 + V1.0 |
| Mount bolt count | 6× M4 | both |
| Phase 1 usage | Feeders at 0/180 (2 active); retainer secures at 60/120/240/300 | architecture |
| Phase 1.5 usage | All 6 bolts shared via stack-mount (bolt → cassette → spacer → retainer) | architecture |
| Spacer requirement | 6× printed spacers D8 × 20 mm (closes gap between cassette top and retainer bottom) | to design |
| Bolt length | M4 × ~50 mm (or threaded rod with nuts) | to verify when ordering |
| Material | PA12 nylon (wear surface, yarn slides on lip underside) | Retainer Ring V1.0 |

### Interface 8: Cassette Base ↔ Ribber  *(Phase 2 provision, unchanged)*

| Property | Value | Locked by |
|---|---|---|
| Bolt PCD | 140.0 | Cassette Base V1.1 (Phase 2 provision) |
| Bolt count | 6× M4 | Cassette Base V1.1 |
| Bolt angular offset | 0° (0/60/120/180/240/300) | Cassette Base V1.1 |
| Used in Phase 1? | NO — holes provisioned, capped/empty | architecture |
| Ribber assembly | NOT DESIGNED YET (deferred to Phase 2) | future |

### Interface 9: Hall Sensor Index  *(elevated in R3)*

| Property | Value | Locked by |
|---|---|---|
| Magnet PCD | 95.0 | Cylinder V3.0 |
| Magnet pocket | D6.0 × 2.2 mm deep (for B0F4KS6KV3 magnets) | Cylinder V3.0 |
| Angular position | 0° (= +X axis = motor side = Slot #0, invariant B4) | Cylinder V3.0 |
| Pulses per revolution | 1 (master index) | architecture |
| Hall sensor part | SS49E (B09MSDC3GR) | BOM_V11 |
| Hall sensor mount | TBD — on bearing housing or motor mount, must face cylinder bottom at PCD 95 | future |

**θ = 0° is the master phase reference for the entire machine.** All
feeder timing, cam phase analysis, ribber sync, and future pattern
control reference this angular origin.

### Interface 10: Touchscreen Mast ↔ Wood Base  *(R3 NEW)*

| Property | Value | Locked by |
|---|---|---|
| Mating method | Dual 2020 uprights + top crossbar, bolted to wood base via T-nuts | R3 |
| Mast base center | (X = 0, Y = −180) world | R3 |
| Mast upright spacing | X = ±30 from mast center | R3 |
| Mast upright length | 400 mm | R3 |
| Top crossbar length | 60 mm | R3 |
| Mast top Z | 418 world (= WOOD_BASE_TOP_Z + MAST_UPRIGHT_LEN) | derived |
| Touchscreen size | 165 × 100 × 10 mm (7" capacitive HDMI) | BOM |
| Touchscreen mount arm | 3D-printed, clamps to crossbar OR uprights | TBD design |
| Mechanical isolation | **NOT connected to precision frame uprights** | invariant C4 |

The touchscreen mast is part of Layer 3 (Automation/Control). Tap
forces, vibration, and resonance from the touchscreen are isolated
from the precision cassette by mounting only to the wood base.

### Interface 12: Shaft / Bearing Stack  *(R5 NEW — formalization)*

The 12 mm drive shaft connects the gearbox-driven 20T pulley (bottom)
to the Drive Hub V2.4.2 (top, which drives the cylinder). The shaft
passes through `BearingHousings V2.5` (top + bottom pair). Until R5
this stack was implied; R5 formalizes the axial constraint strategy.

**Architecture: floating top, fixed bottom.**

```
Drive Hub V2.4.2  (top of shaft)
  └ pressed onto / clamped on shaft top
     ↑ shaft Z = drive hub bottom Z

     ░ 12 mm drive shaft (FEYRINX h8, B08HX2LG53, 300 mm) ░

UPPER bearing 6001-2RS   ── floating axially
  │ inside upper bearing housing seat
  │ axial gap on both sides (no preload from above)
  │ rotates freely; absorbs shaft thermal growth
  ↓

LOWER bearing 6001-2RS   ── axially fixed
  │ inside lower bearing housing seat
  │ inner race clamped between shaft collar (above) and 51101 thrust (below)
  ↓
51101 thrust bearing     ── axial load path
  │ takes upward cassette/yarn force AND downward belt-pull component
  │ sits between lower 6001 inner race and shaft collar #2
  ↓
Shaft collar #2 (12 mm)  ── axially clamps the stack
  │ B0DMMB1FHF
  │ tightened against thrust bearing inner race
  ↓
Pulley HTD 20T (12 mm bore)
  │ pinned/grub-screwed to shaft
  │ sits BELOW the lower bearing -- belt overhang below frame
  ↓ shaft bottom
```

**Why floating-top, fixed-bottom:**
- Axial load on shaft is primarily DOWNWARD (cassette weight + yarn tension + belt-pull component) → resolved at lower thrust bearing
- Upward load is small (only momentary during yarn pull-up events) → also resolved at lower thrust (51101 takes load in both directions)
- Upper bearing is purely RADIAL — no axial constraint → allows shaft thermal growth without binding
- Belt side-load on shaft below lower bearing → cantilever moment; lower bearing handles the radial component, upper bearing stabilizes the moment couple

| Property | Value | Locked by |
|---|---|---|
| Shaft | FEYRINX 12 mm h8 hardened, 300 mm length, ground finish | BOM B08HX2LG53 |
| Upper bearing | 6001-2RS (28 OD × 12 ID × 8 W) — radial only, axial-float seat | BOM |
| Lower bearing | 6001-2RS (28 OD × 12 ID × 8 W) — radial + fixed axially | BOM |
| Thrust bearing | 51101 (28 OD × 12 ID × 9 W) — under lower 6001 | BOM B0G25X5L23 |
| Shaft collars | 12 mm clamping collars (4-pack, B0DMMB1FHF) — 2 used minimum | BOM |
| Bearing housing | `BearingHousings V2.5.1` (printed PETG) | locked |
| Axial constraint | LOWER bearing fixed; UPPER bearing floating | R5 invariant |
| Pulley axial position | BELOW the lower bearing pair (i.e. extending below Bearing Housing bottom) | R5 |
| Preload | LIGHT — Smalley CM25-L1 wave spring optional (BOM Section 3) | R5 |
| Service | Pulley + collar removal via SE5 (belt replacement) | SERVICE_ENVELOPES.md |

**Design rules (DO):**
- ✅ Lock lower bearing inner race against shaft collar + thrust bearing as a sandwich
- ✅ Leave the upper bearing inner race FREE on the shaft (slip fit, no collar above it)
- ✅ Apply Loctite 603 only to the lower 6001 outer race if seat is loose; never on the upper bearing
- ✅ Pulley grub screw uses Loctite 222 (low-strength, removable)

**Design rules (DON'T):**
- ❌ Do NOT clamp BOTH bearings axially. Will preload the shaft and bind under thermal growth.
- ❌ Do NOT mount the pulley BETWEEN the two bearings. Belt side-load between bearings inverts the load path and amplifies wobble.
- ❌ Do NOT replace the 51101 thrust with another 6001 radial. Radial bearings don't take pure axial loads cleanly.

This interface is now part of the DO-NOT-BREAK invariant set (added below as A8). Changes require R5 → R6 with full bearing-stack review.

---

### Interface 11: Sock Take-Down Column  *(R3 NEW)*

| Property | Value | Locked by |
|---|---|---|
| Geometry | Vertical column on cylinder axis (world X = Y = 0) | invariant C2 |
| Upper boundary | Drive hub bore exit (world Z ≈ 170) | derived |
| Lower boundary | Through D100 hole in wood base (world Z = 0 → ‑∞) | R3 |
| Wood base hole diameter | 100.0 mm | R3 |
| Hole clearance | radius 50 mm clear of any structure | R3 invariant |
| Phase 1 take-down method | **Hanging weight (manual)** — BRING-UP TOOL ONLY | R6 |
| Phase 2 take-down method | **Dual-roller servo-controlled nip system** | R6 (specified) |
| Phase 3 take-down method | Closed-loop tension with optical length sensing (or vacuum) | future |
| Obstruction rule | NO motors, electronics, cables, or structural members may occupy this column | invariant C2 |

Forgetting this column is the single most common architecture mistake
in DIY circular sock machines. Without it, knit fabric climbs, stitch
tension destabilizes, and dropped stitches multiply. The column is
**reserved space** even in Phase 1 where only a hanging weight uses
it.

**R6 Design Rule — Take-down tension is a stitch-formation parameter,
not a fabric-handling parameter.**

Phase 1.5 D-4b simulator results proved this: scenario B1 (slack)
shows that ±2 mm of yarn slack changes capture margin sign. Since
slack is governed by take-down tension, take-down tension is
*coupled* to stitch formation — not downstream of it.

Implications:

- ✅ Phase 1 hanging weight = isolation tool: lets us tune the
  cassette / cam / yarn-capture mechanics WITHOUT a second
  coupled control system (powered take-down dynamics).
- ✅ Adjustable / stackable weights during bring-up are valuable:
  they let us sweep take-down tension experimentally without
  changing firmware or motor controllers.
- ❌ Hanging weight is NOT the production solution. Sock fabric mass
  grows during knitting (1 g/round to 50+ g for a full sock), so a
  fixed-mass weight gives varying tension. Production needs
  active control.
- 🔄 Phase 2 architecture: **dual-roller servo-controlled nip**.

**Phase 2 take-down architecture (R6 specified):**

```
   fabric tube exits cylinder bore
       ↓
   ┌─────────────────────────────────┐
   │  driven roller (rubber-coated)  │ ← stepper or DC gearmotor
   │  ~25 mm OD × 80 mm long          │   pulls fabric at controlled rate
   │  ───[sock fabric]───             │   synced to cylinder rotation
   │  spring-loaded idler roller      │ ← nip pressure
   │  ~25 mm OD × 80 mm long          │
   └─────────────────────────────────┘
       ↓
   encoder or tension sensor (closed-loop)
       ↓
   sock exits to collection bin
```

Properties:
- Compact under-base packaging (fits within Interface 11 column)
- Low inertia (responds quickly to commanded rate changes)
- Easy speed synchronization (target: ~5–10 mm fabric per cylinder revolution)
- Scalable: can add tension-feedback loop in Phase 3
- Acceptable in Phase 2 without full closed-loop (open-loop rate
  control is usually adequate once tuned)

NOT chosen alternatives and why:
- Vacuum extraction: requires blower + ducting + cleaning of lint;
  larger packaging; harder to test/iterate.
- Conveyor: doesn't fit the Ø100 column; fabric doesn't ride flat.
- Constant-force spring: works in theory but harder to design than
  servo nip in a one-off prototype.

---

## §4  Upgrade Path (Phases)

| Phase | Goal | Components added | Validation |
|---|---|---|---|
| **1** | Static architecture + 2-feeder Phase 1 build | Frame, drive train, 2 feeder modules, basic electronics, manual yarn management | Visual render proves architecture; first physical assembly |
| **1.5** | **Kinematic truth validation** (NEW gate) | None new — Blender motion study of: needle lift through 8 mm cam cycle, hook trajectory, feeder yarn intercept, retainer clearance, sinker timing | Blender animation + collision check before any feeder hardware is printed |
| **2** | 6 active feeders, color changes, ribber disk | 4 more feeder modules at 60/120/240/300, ribber assembly at PCD 140, yarn tension feedback | Multi-feed knit test, pattern complexity test |
| **3** | Closed-loop intelligent system | Vacuum take-down (in column from Interface 11), electronic patterning, automatic heel/toe shaping, optical length sensing | Production-quality sock output |

Each phase's components mount via interfaces defined here. No phase
requires re-architecting the precision core, the frame, or the
coordinate system. This is enabled by the invariants section above.

---

## §5  Locked Versions

| Component | Version | Layer | Macro file |
|---|---|---|---|
| Cylinder | **V3.1** (locked 2026-05-24 from WEDGE_B V2 physical test, slot 7) | 1 | `02_CASSETTE_HEAD/cylinder/freecad_macros/CSM_V3_Cylinder_V3_0.FCMacro` (file unchanged, internal version V3.1) |
| Cam Ring | V6.5 (FINAL) | 1 | `02_CASSETTE_HEAD/cam_ring/freecad_macros/CSM_V3_CamRing_V6_5.FCMacro` |
| Sinker Ring | V1.2.1 (LOCKED) | 1 | `02_CASSETTE_HEAD/sinker_ring/freecad_macros/CSM_V3_SinkerRing_V1_2_1.FCMacro` |
| Cassette Base | V1.1 | 1 | `02_CASSETTE_HEAD/cassette_base/freecad_macros/CSM_V3_CassetteBase_V1_1.FCMacro` |
| Retainer Ring | V1.0 (LOCKED) | 1 | `02_CASSETTE_HEAD/retainer_ring/freecad_macros/CSM_V3_RetainerRing_V1_0.FCMacro` |
| Cassette Spacer (×6) | V1.0 (LOCKED 2026-05-24) | 1 | `02_CASSETTE_HEAD/cassette_spacers/freecad_macros/CSM_V3_CassetteSpacer_V1_0.FCMacro` |
| Drive Hub | V2.4.2 (Done) | 2 | `06_DRIVE_SYSTEM/freecad_macros/CSM_V3_DriveHub_V2_4_2.FCMacro` |
| Motor Mount | V1.3 (**OBSOLETE for drive** — V1.4 needed for NEMA 23 + gearbox) | 2 | `06_DRIVE_SYSTEM/freecad_macros/CSM_V3_MotorMount_V1_3.FCMacro` |
| Bearing Housings | V2.5 (Done) | 2 | `05_BEARINGS_SHAFT/freecad_macros/CSM_V3_BearingHousings_V2_5.FCMacro` |
| Wood Base | V1.0 (NEEDS V1.1 — add D100 take-down hole) | 2 | `CSM_V3_ASSEMBLY/frame/wood_base/freecad_macros/CSM_V3_WoodBase_V1_0.FCMacro` |
| Wood Upper Deck | **NOT YET** | 2 | to build at `CSM_V3_ASSEMBLY/frame/wood_upper_deck/` |
| Aluminum Plate | V1.0 (NEEDS V1.1 — resize 150 → 250) | 2 | `CSM_V3_ASSEMBLY/frame/mount_plate_6061/freecad_macros/CSM_V3_MountPlate6061_V1_0.FCMacro` |
| 2020 Upright | V1.0 (NEEDS V1.1 — shorten 267 → 188, reposition) | 2 | `CSM_V3_ASSEMBLY/frame/upright_2020/freecad_macros/CSM_V3_Upright2020_V1_0.FCMacro` |
| Touchscreen Mast | **NOT YET** | 3 | to build at `CSM_V3_ASSEMBLY/frame/touchscreen_mast/` |
| ~~NEMA 17 motor (drive)~~ | **OBSOLETE** — replaced by NEMA 23 + gearbox | 3 | `CSM_V3_ASSEMBLY/drive_bought/nema17_stepper/` (archive) |
| NEMA 23 + 5:1 gearbox (drive) | **NEEDS BUILD** | 3 | `CSM_V3_ASSEMBLY/drive_bought/nema23_gearbox/` (to create) |
| HTD 60T pulley (14 mm bore) | V1.0 (built — verify bore) | 3 | `CSM_V3_ASSEMBLY/drive_bought/pulley_htd_60t/` |
| HTD 20T pulley (12 mm bore) | **NEEDS BUILD** (was 16T in R3) | 3 | `CSM_V3_ASSEMBLY/drive_bought/pulley_htd_20t/` (to create) |
| HTD belt 405 mm | V1.0 (built) | 3 | `CSM_V3_ASSEMBLY/drive_bought/belt_htd_5m/` |
| Bearings + shaft | NOT YET | 3 | `CSM_V3_ASSEMBLY/bearings_bought/` |
| Feeder Module | **V1.2E** (first-print candidate 2026-05-27 — adjustable ceramic-pigtail clamp, MG90S servo cavity, ±3 mm tangential + ±20° rotational tuning; V1.0 / V1.1 archived) | 3 | `CSM_V3_ASSEMBLY/feeder_module/freecad_macros/CSM_V3_FeederModule_V1_2E.FCMacro` |
| Electronics (Mega/TB6600/S-250/Pi 4) | V1.0 boxes built; cable routing TBD | 3 | `CSM_V3_ASSEMBLY/electronics/` |
| MG90S servo (×6 + 2 spare) | NOT YET as STL | 3 | to add at `CSM_V3_ASSEMBLY/electronics/servo_mg90s/` |
| LM2596 buck converter | NOT YET as STL | 3 | to add at `CSM_V3_ASSEMBLY/electronics/lm2596_buck/` |
| Touchscreen 7" | NOT YET | 3 | `CSM_V3_ASSEMBLY/electronics/touchscreen_7in/` |
| Take-Down Hook Adapter | **V1.0H** (current candidate — D3.0 hooks, 8 mm length, 2 mm root fillet, 3.2× stronger than V1.0F); **V2.0** (architectural alternative — wire-hook carrier, available if printed PETG hooks prove inadequate after failure diagnosis per Phase 1 Guide §3.5). Status PENDING physical failure-mode diagnosis. | 1 | V1.0H: `CSM_V3_ASSEMBLY/take_down/freecad_macros/CSM_V3_TakeDownHookAdapter_V1_0H.FCMacro` • V2.0 (alt): `…/CSM_V3_TakeDownHookAdapter_V2_0.FCMacro` |
| Needle Set & Index Collar | **V1.0A** (Phase 1 assembly aid, 2026-05-27 — clips over cyl OD, datum hub on top face, 72 segmented push pads set uniform needle height, 72 index notches; `NEEDLE_SET_H=9.0` PROVISIONAL, lock to V1.0B after first physical needle measurement) | 1 (tooling) | `CSM_V3_ASSEMBLY/needle_jig/freecad_macros/CSM_V3_NeedleSetCollar_V1_0A.FCMacro` |
| Ribber (Phase 2) | provisioned only | 1 | future |

---

## How to Use This Document

**When designing a new component:**
1. Identify which layer (1/2/3) it belongs to
2. Find every interface this component touches (e.g. Feeder Module → I5)
3. Copy the locked values exactly into the component's macro parameter section
4. Verify your component does not intrude into any SE1–SE5 service envelope or the Interface 11 take-down column
5. Do NOT modify locked values without going through the change process below

**When proposing an interface change:**
1. Determine whether the change touches an invariant in the DO-NOT-BREAK block. If yes, it is a full ICD revision (R3 → R4).
2. Identify all mating parts that depend on the interface
3. Decide whether to absorb the change in one part or split between both
4. If split, bump BOTH parts' versions
5. Update this document; update `MACHINE_DATUMS.md` if a datum shifted
6. Re-validate all 5 service envelopes
7. Commit all changes together with a clear message describing what changed and why

---

## Revision History

| Rev | Date | Changes |
|---|---|---|
| R1 | 2026-05-17 | Initial ICD. Captures interfaces 1-9 from locked V3 architecture. |
| R2 | 2026-05-17 | Lock Interface 7 with Retainer Ring V1.0 final geometry. Retainer OD = 200 (was 172, fixed for bolt PCD compatibility). All other interfaces unchanged. |
| R3 | 2026-05-20 | Major architectural revision. (a) NEW DO-NOT-BREAK invariants block (machine constitution); (b) NEW §0 three-layer architecture; (c) NEW §1 datum chain; (d) NEW §2 service envelopes SE1–SE5 (summary; full doc in `SERVICE_ENVELOPES.md`); (e) Interface 5 updated (NEMA 11 feeder motors, FEEDER_REFERENCE_Z 78→90 provisional); (f) Interface 6 major rewrite (frame architecture: wood base 500×400 w/ D100 hole + 4× 2020 uprights at ±150 ±120 × 188 mm + wood upper deck 320×260×18 + aluminum plate 250×250×6 master datum). The R2 "wood mid-shelf 500×400" is DELETED; (g) Interface 9 elevated (θ=0° = master phase reference); (h) NEW Interface 10 (Touchscreen Mast — dual 2020, isolated from precision frame); (i) NEW Interface 11 (Sock Take-Down Column — D100 through wood base, reserved space invariant); (j) NEW §4 Phase 1/1.5/2/3 upgrade path with kinematic-validation gate at 1.5; (k) §5 locked-versions refreshed with layer assignment + new components flagged NEEDS V1.1 or NOT YET. |
| R4 | 2026-05-22 | **BOM ALIGNMENT.** Reconciled Interface 5 + Interface 6 with the actual physical inventory in `04_PURCHASING/BOM_V11/CSM_V3_BOM_V11.html`. (a) **Interface 5 feeder actuator**: NEMA 11 stepper → **MG90S metal-gear servo** (8 purchased: 6 active + 2 spare). PWM not step/dir. Feeder Module V1.0 cavity needs V1.1 redesign for 23×13 servo footprint. (b) **Interface 6 drive motor**: NEMA 17 → **NEMA 23 + 5:1 planetary gearbox (23HS22-2804S-HG5)** ($95 StepperOnline). Body 57×57×56 + 50 mm gearbox = 106 mm total. Motor Mount V1.3 OBSOLETE → V1.4 needed (M5 PCD 47.14 vs old M3 PCD 31). (c) **Interface 6 pulleys**: HTD 5M 60T+16T → actual **60T+20T+405mm belt** (kit B0C6Y1462P). New belt ratio 3:1; total reduction = 5×3 = **15:1**. Big pulley bore 12→14 mm (gearbox shaft). (d) §5 locked-versions table refreshed: NEMA 17 STL flagged OBSOLETE; NEMA 23+gearbox STL needs build; 20T pulley needs build; Feeder Module V1.1 needed. All invariants in DO-NOT-BREAK section unchanged. |
| R5 | 2026-05-22 | **Shaft-stack formalization + feeder control philosophy.** (a) NEW **Interface 12** (Shaft / Bearing Stack) — formalizes the floating-top / fixed-bottom bearing architecture on the 12 mm drive shaft. Lower 6001 + 51101 thrust + shaft collar resolves axial load; upper 6001 floats radially to allow thermal growth. Pulley sits BELOW lower bearing (not between). DO / DON'T design rules added. (b) NEW **invariant A8**: shaft bearing stack architecture is now part of the DO-NOT-BREAK invariant set. (c) NEW **R5 Design Rule** under Interface 5: MG90S feeders are "guided yarn presentation," NOT precision synchronized actuation. Defines which feeder operations are acceptable in Phase 1 vs. require a Phase 2 stepper upgrade. (d) Updated revision banner to reflect R5 scope. |
| R6 | 2026-05-24 | **Take-down as stitch-formation parameter (Interface 11 elevation).** Phase 1.5 D-4b results showed scenario B1 (slack) reaches catastrophic capture failure at only ±2 mm slack — proving take-down tension is *coupled to* stitch formation, not downstream of it. (a) NEW **R6 Design Rule** under Interface 11: "Take-down tension is a stitch-formation parameter, not a fabric-handling parameter." Explains why hanging weight (Phase 1) is a bring-up / isolation tool, not the production solution. (b) **Phase 2 take-down architecture formally specified**: dual-roller servo-controlled nip system (rubber drive roller + spring-loaded idler + stepper/DC gearmotor + encoder closed-loop). Replaces vague R3 "weighted claw / roller system" placeholder. (c) Documented why alternatives (vacuum, conveyor, constant-force spring) were not chosen for Phase 2. (d) Phase 3 take-down now specified as closed-loop tension with optical length sensing (or vacuum-assist as alternative). |

---

## Cross-References

- **Coordinate authority:** `MACHINE_COORDINATE_SYSTEM.md` (R1)
- **Dimensional reference:** `MACHINE_DATUMS.md` (R2 final)
- **Service envelopes (full):** `SERVICE_ENVELOPES.md` (next deliverable)
- **Project overview:** `~/.claude/projects/C--3D-Project/memory/project_csm_v3_overview.md`
- **BOM:** `04_PURCHASING/BOM_V11/CSM_V3_BOM_V11.html`
- **Phase 1.5 kinematic script:** future `full_assembly/blender_scripts/needle_motion_study.py`

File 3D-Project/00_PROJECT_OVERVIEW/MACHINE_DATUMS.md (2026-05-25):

# MACHINE_DATUMS.md — CSM V3 Dimensional Reference

```
Revision:  R5
Date:      2026-05-24
Status:    Active — all macros must reference these constants.
           R5 locks SLOT_DEPTH and SPRING_GROOVE_DEPTH to production
           values derived from physical Phase-1 testing. Cylinder
           bumped V3.0 → V3.1.
```

This is the **single source of truth for all dimensional constants**
used across the CSM V3 project: cylinder-local datum planes, key
interface diameters, bolt patterns, frame geometry, and bought-parts
dimensions.

**Coordinate convention authority** has moved to a sister document:
`MACHINE_COORDINATE_SYSTEM.md` (R1). That doc defines the world frame,
the cylinder-local frame, and the `CYL_BOTTOM_WORLD_Z = 181 mm`
transform. This document focuses on **what things measure**, not where
they sit in world space.

Every machine-component macro MUST:
1. Reference these values by name (e.g. `CAM_DATUM_Z`), never by raw number
2. Copy the relevant constants block verbatim into its parameter section
3. Update this document FIRST when any datum changes, then sync macros
4. Follow `MACHINE_COORDINATE_SYSTEM.md` for any world-coordinate placement

---

## Cylinder-Local Z Datum Planes

All Z values below are **cylinder-local** (Z=0 at cylinder bottom face,
where it sits on the drive hub boss). To convert to world Z, add
`CYL_BOTTOM_WORLD_Z = 181.0` (see `MACHINE_COORDINATE_SYSTEM.md`).

```python
# ============================================================
# CYLINDER-LOCAL DATUMS  (copy verbatim into every cassette macro)
# ============================================================
CYLINDER_Z0          =  0.0    # cylinder bottom (= drive hub boss top)
CAM_DATUM_Z          = 49.0    # cam ring top / cassette base bottom
CASSETTE_TOP_Z       = 63.0    # outer disc top of cassette base
SINKER_Z             = 75.0    # sinker register plane (assembly reference)
CYLINDER_TOP_Z       = 75.0    # cylinder top face (geometry reference)
                                # Same numerical value as SINKER_Z but
                                # semantically distinct. Future variants
                                # may decouple them — keep both names.
FEEDER_REFERENCE_Z   = 90.0    # nominal feeder finger height
                                # CHANGED from R1 (was 78). Raised to
                                # match retainer/sinker geometry. Final
                                # value validated in Phase 1.5
                                # (kinematic motion study).
HOOK_PEAK_Z          = 83.0    # needle hook position at peak cam lift
                                # (cylinder top Z=75 + 8mm cam lift)
                                # Equal to retainer ring bottom plane
                                # in world coords (264 mm). Kinematic
                                # boundary — affects retainer lip
                                # clearance, feeder approach angle,
                                # ribber timing, knock-over geometry.
```

### Cylinder-local visualization

```
              Z=91  ─── retainer ring top (geometry-derived)
              Z=90  ─── FEEDER REFERENCE  (validated in Phase 1.5)
              Z=83  ─── HOOK PEAK         (= retainer bottom = world 264)
                         (yarn caught here, just above cylinder top)
              Z=75  ─── SINKER PLANE / CYLINDER TOP
                         (sinker ring sits here, cylinder top face)
              Z=63  ─── CASSETTE BASE TOP (outer disc upper surface)
              Z=49  ─── CAM DATUM (cam ring top / cassette base bottom)
                         (= world Z 230 = aluminum plate top
                          = MASTER DATUM for the whole machine)
              Z=19..31 ── cam track engagement (butt zone)
              Z=0   ─── CYLINDER BOTTOM (drive hub interface)
```

### World-Z mapping (derived from local datums + CYL_BOTTOM_WORLD_Z = 181)

**Semantic note:** `CAM_DATUM_Z` (cylinder-local) and `ALU_PLATE_TOP_Z`
(world) are **physically coincident** at world Z = 230 mm in the
nominal assembly — but they are **not the same datum**. The cassette's
local frame ends at `CAM_DATUM_Z`; the machine's master datum is
`ALU_PLATE_TOP_Z`. Any future shim/spacer between cassette bottom and
plate top will offset these two without violating either definition.

| Physical interface plane | Cylinder-local Z | World Z | Notes |
|---|---:|---:|---|
| CYLINDER_Z0 (cylinder bottom face) | 0 | 181 | drive hub boss interface |
| Cam track top engagement | 31 | 212 | upper limit of butt travel |
| **CAM_DATUM_Z** (cam ring top = cassette base bottom) | 49 | 230 | local datum, coincident with master datum below |
| **ALU_PLATE_TOP_Z** (machine master datum plane) | — | **230** | world reference, cassette mounts here |
| CASSETTE_TOP_Z (outer disc top) | 63 | 244 | cassette base outer-disc top face |
| SINKER_Z / CYLINDER_TOP_Z | 75 | 256 | numerically equal, semantically distinct |
| HOOK_PEAK_Z | 83 | 264 | = retainer bottom plane |
| FEEDER_REFERENCE_Z | 90 | 271 | provisional; Phase 1.5 validates |
| Retainer top (macro-derived, RR_THICK = 8 mm) | 91 | 272 | per Retainer Ring V1.0 geometry |

`RETAINER_ASSEMBLY_OFFSET_Z = 0` in nominal assembly. Any future Z
shim between retainer and cassette is recorded by raising this value
in the assembly script — not by editing the retainer macro.

---

## Derived Values (DO NOT EDIT DIRECTLY)

These values are **computed** from the primary constants above. If
the primary value changes, the derived value updates automatically.
Hard-coding a derived value as a literal in a macro is a bug.

```python
# ============================================================
# DERIVED VALUES -- computed from primary constants. Read-only.
# ============================================================

# --- Cassette / cylinder kinematics ---
HOOK_LIFT             = HOOK_PEAK_Z - CYLINDER_TOP_Z      # = 8.0 mm  (cam stroke)
CASSETTE_DISC_THICK   = CASSETTE_TOP_Z - CAM_DATUM_Z      # = 14.0 mm (cassette outer disc)
SINKER_TO_HOOK_GAP    = HOOK_PEAK_Z - SINKER_Z            # = 8.0 mm  (yarn catch window)
FEEDER_ABOVE_HOOK     = FEEDER_REFERENCE_Z - HOOK_PEAK_Z  # = 7.0 mm  (yarn drop distance, provisional)

# --- Frame Z stack ---
UPRIGHT_BOT_Z         = WOOD_BASE_TOP_Z                    # = 18.0
UPRIGHT_TOP_Z         = UPRIGHT_BOT_Z + UPRIGHT_LEN        # = 206.0
UPPER_DECK_BOTTOM_Z   = UPRIGHT_TOP_Z                      # = 206.0
UPPER_DECK_TOP_Z      = UPPER_DECK_BOTTOM_Z + UPPER_DECK_T # = 224.0
ALU_PLATE_BOTTOM_Z    = UPPER_DECK_TOP_Z                   # = 224.0
ALU_PLATE_TOP_Z       = ALU_PLATE_BOTTOM_Z + ALU_PLATE_T   # = 230.0 (master datum)
CYL_BOTTOM_WORLD_Z    = ALU_PLATE_TOP_Z - CAM_DATUM_Z      # = 181.0 (= the transform constant)

# --- Service envelope SE5 derived geometry ---
BELT_TENSION_X_RANGE  = (MOTOR_X - BELT_TENSION_TRAVEL, MOTOR_X)   # = (60, 90)
                       # motor shall be free to translate in this X range
                       # for belt tension + removal (see SERVICE_ENVELOPES.md)
```

Build-time invariant: `CYL_BOTTOM_WORLD_Z` from the derived block
MUST equal the constant defined in `MACHINE_COORDINATE_SYSTEM.md`
(181.0). If frame Z stack ever changes such that the two diverge,
either the frame Z stack is wrong or the coordinate system constant
is wrong — fix the cause, not the symptom.

---

## Angular Phase Reference (θ = 0°)

```
═══════════════════════════════════════════════════════════════
θ = 0° MACHINE PHASE REFERENCE
═══════════════════════════════════════════════════════════════
  - Cylinder slot #0 aligned with +X axis (motor side)
  - Hall sensor index magnet at PCD 95 on bottom face,
    at angular position 0° (Cylinder V3.0 geometry)
  - Hall sensor index pulse occurs once per cylinder revolution
    when slot #0 crosses the sensor
  - All feeder timing, future pattern control, ribber sync, and
    heel/toe sequencing reference this phase origin
  - Rotation direction: CCW looking from +Z (standard knitting)
```

This is **foundational** for Phase 1.5 kinematic validation and all
subsequent automation. Changing θ = 0° alignment is a breaking
architectural change requiring an ICD revision bump.

---

## Cassette Geometry (cylindrical / rotational centerlines)

All concentric on the cylinder Z axis (world X=Y=0).

| Feature | Diameter (mm) | Notes |
|---|---:|---|
| Cylinder OD | 114.30 | Legare 4.5" standard (LOCKED ICD invariant #1) |
| Cylinder ID (bore) | 88.00 | sock take-down passage |
| Slot bottom (radial) | 107.50 | OD − 2 × slot_depth (3.0 mm) |
| Cam Ring ID | 115.00 | 0.35 mm/side clearance to cylinder OD |
| Cam Ring OD | 165.00 | locked per Cam Ring V6.5 |
| Cassette Base center hole | 117.00 | 1.35 mm total clearance |
| Sinker Pedestal ID | 128.00 | annular pedestal inner edge |
| Sinker Pedestal OD | 150.00 | annular pedestal outer edge |
| Sinker register pocket | 135.30 | sinker OD 135 + 0.3 slip fit |
| Sinker Ring OD | 135.00 | mates with register pocket |
| Sinker Ring ID | 115.30 | 0.5 mm/side clearance to cylinder OD |
| Cassette Base OD | 200.00 | structural foundation |
| Retainer Ring OD | 200.00 | matches cassette base OD |
| Retainer Ring through-bore | 118.00 | cylinder OD 114.3 + 1.85 mm radial clearance |
| Retainer loop-control lip ID | 104.00 | effective loop aperture |

---
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

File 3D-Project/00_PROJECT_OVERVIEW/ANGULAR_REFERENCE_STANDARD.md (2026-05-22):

# ANGULAR_REFERENCE_STANDARD.md — CSM V3 Top-View Angular Convention

```
Revision:  R1
Date:      2026-05-20
Status:    Active — canonical angular reference. Locks all angular
           positions on the cylinder, cam ring, sinker, retainer,
           cassette base, feeder modules, sensors, and assembly
           coordinates.
```
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

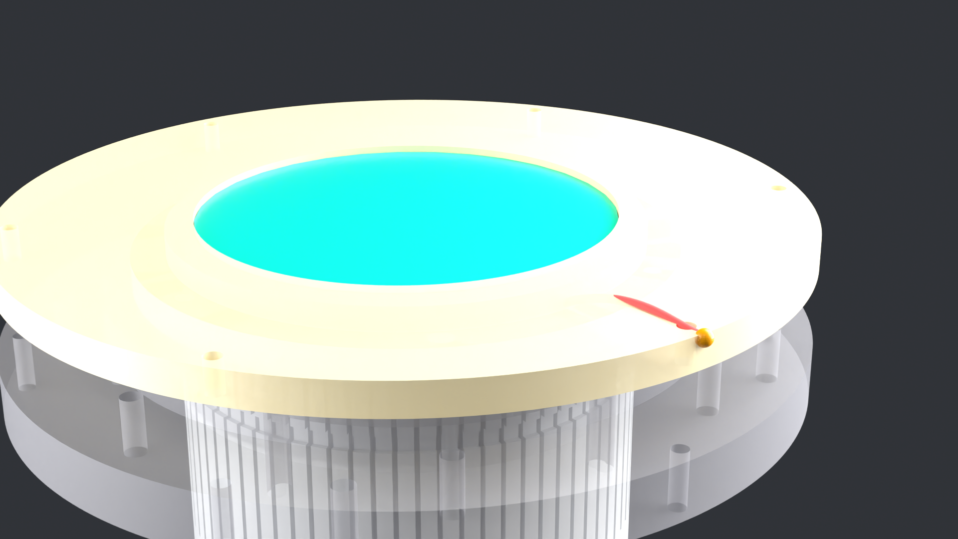
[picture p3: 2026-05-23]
CSM_V3_ASSEMBLY/full_assembly/renders/CSM_V3_KinematicTriad_K_triad_3q.png

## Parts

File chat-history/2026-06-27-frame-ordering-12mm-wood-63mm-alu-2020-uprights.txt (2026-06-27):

# CSM V3 -- SESSION LOG  2026-06-27
# Scope: Frame parts ordering session -- wood/aluminum/extrusion specs
#        finalized for actual supplier availability and existing BOM
# Files: 4 commits, all pushed to origin/main; STEP files added for shop CNC

================================================================
HEADLINE OUTCOMES
================================================================

1. Aluminum master-datum plate moved from 6.0 -> 6.3 mm (1/4" stock)
   - User's supplier offered 4.7 mm or 6.3 mm; 6.3 chosen
   - 2.4x stiffer than 4.7 (t^3 scaling)
   - Better flatness retention during stress-relief after machining
   - Cost delta only $5-15 vs 4.7
   - PLATE ORDERED at 250 x 250 x 6.3 mm 6061-T6 mill finish

2. Wood thickness moved 18 -> 12 mm (Baltic Birch supplier max)
   - User searched multiple suppliers for 18 mm Baltic Birch ply, none
     stocked at home wood shop they were using
   - Tried 12 mm version, reverted to 18 mm, then user found 12 mm
     supplier and ordered
   - BOTH WOOD PIECES ORDERED at 12 mm:
     * Wood base:       500 x 400 x 12 mm Baltic Birch
     * Wood upper deck: 320 x 260 x 12 mm Baltic Birch

3. 2020 uprights: 188 -> 200 mm cut length to compensate for thinner
   wood (6 mm + 6 mm = 12 mm height lost from two wood layers)
   - User confirmed B0D89YS5VP (BOM) is 500 mm x 4 V-slot black
   - More than enough material (2000 mm total, need 800 mm)
   - Will cut at home or local shop

4. ICD R3 master datum at Z=230 (invariant B3) PRESERVED
   - Stack rebalanced: 12 wood + 200 upright + 12 wood + 6.3 plate
     = 230.3 nominal; CAD-exact upright at 199.7 to land plate top
     at Z=230. Cut tolerance absorbs the 0.3 mm.

================================================================
TODAY'S Z-STACK (FINAL)
================================================================

  Z=0      ← wood base bottom (floor)
  Z=12     ← wood base top / upright bottom        (was 18)
  Z=211.7  ← upright top / upper deck bottom       (was 206)
            CAD upright length = 199.7 mm; practical cut = 200 mm
  Z=223.7  ← upper deck top / aluminum plate bottom (was 224)
  Z=230.0  ← MASTER DATUM (top of plate, LOCKED)

================================================================
DXF / STEP / PDF GENERATION
================================================================

Per user observation: DXF is 2D-only and shops cannot see thickness.
SHOP DELIVERABLE for each frame part = 3 files:
   .step  - 3D solid model (thickness embedded, no ambiguity)
   .dxf   - 2D cut path (CNC router input)
   .pdf   - human-readable drilling drawing

STEP file generation added to generate_drawings.py:
   _make_wood_base_solid()       -> 500x400x12 + 22 holes
   _make_wood_upper_deck_solid() -> 320x260x12 + 9 holes
   _make_alu_plate_solid()       -> 250x250x6.3 + 5 holes
   generate_step_files()         -> wraps Part.export

All filenames now include explicit thickness in name (so file system
is unambiguous):
   CSM_V3_WoodBase_V1_1_500x400x12.{dxf,step}
   CSM_V3_WoodUpperDeck_V1_0_320x260x12.{dxf,step}
   CSM_V3_MountPlate6061_V1_1_250x250x6_3.{dxf,step}

================================================================
FRAME DRAWINGS REORGANIZED
================================================================

Earlier today: drawings were initially saved under
electronics/drawings/ because that's where the matplotlib generator
lives. User correctly pointed out frame parts should live with their
frame folders.

Reorganized (git mv preserving history):
   electronics/drawings/wood_base.dxf
     -> frame/wood_base/CSM_V3_WoodBase_V1_1_500x400x12.dxf
   electronics/drawings/wood_upper_deck_drilling.{pdf,png}
     -> frame/wood_upper_deck/CSM_V3_WoodUpperDeck_V1_0_drilling.{pdf,png}
   electronics/drawings/aluminum_plate_drilling.{pdf,png}
     -> frame/mount_plate_6061/CSM_V3_MountPlate6061_V1_1_drilling.{pdf,png}

generate_drawings.py updated with FRAME_DIRS dict so future regens
write to the correct folders directly.

Electronics-specific drawings remain in electronics/drawings/:
   wood_base_top.pdf (electrical-mount drilling layout)
   drilling_guide.pdf (electronics hole coordinate table)
   operator_panel.pdf
   components_card.pdf
   hardware_order_sheet.pdf
   assembly_procedure.{pdf,png}
   bench_test_checklist.{pdf,png}

================================================================
BOM VERIFICATION
================================================================

User asked "did you check buy list?" before I suggested ordering
2020 uprights. CORRECT -- everything was already on BOM V12:

   B0D89YS5VP   2020 V-slot 500 mm x 4 (frame uprights)    ORDERED
   B0D89Y43YK   2020 extrusion 400 mm x 2 (touchscreen mast) ORDERED
   B0FLD88X6Y   Corner brackets for 2020                    ORDERED
   B0GG4N5GR4   M5 T-nuts 230pk                             ORDERED
   B0DPQJ4W3Z   M5 brass heat-set inserts                   ORDERED

User has 500 mm sticks, not pre-cut 188 mm. Needs to cut to 200 mm
each. 2000 mm material total, only 800 mm needed for 4 uprights,
1200 mm spare for future mods or touchscreen mast.

Cut tolerance: +/- 1.0 mm acceptable (+/- 0.5 better).
Squareness: critical for upright verticality (wood bolts to ends).

STILL MISSING FROM BOM (safety items before powered test):
   - E-stop mushroom 22mm panel mount, NC+NC, 10A/250V
   - IEC C14 panel-mount AC inlet
   - 2A T-fuse panel-mount holder
   - Status LEDs (green + amber 5 mm) -- optional

================================================================
PERMISSION ALLOWLIST EXPANSION (local, not in repo)
================================================================

User frustrated with frequent permission prompts. Expanded
C:\3D-Project\.claude\settings.json from 7 patterns to 50+:
   - All "Get-*" PowerShell cmdlets
   - All "Test-*", "Select-*", "Format-*", "Where-*", "Sort-*",
     "Measure-*", "ForEach-*", "Resolve-*", "Split-*", "Join-*",
     "Convert-*"
   - "Start-Sleep", "Out-*" pipeline operations
   - Bash read-only git subcommands
   - Read(*), Edit(*), Write(*), Glob(*), Grep(*) -- broad file access
   - All MCP github read-only operations
   - mcp-registry read operations

Honest note to user: cannot allowlist arbitrary code execution
(Python, FreeCAD, etc.) or destructive ops (git push, Remove-Item)
per safety constraints. Those continue to prompt.

NOT committed to repo (machine-specific settings).

================================================================
GIT COMMITS THIS SESSION (chronological)
================================================================

55e7348  Move frame drawings to their proper folders (not under
         electronics/)
f658a60  Add STEP files (3D solid models) for the 3 CNC frame parts
a870c80  Aluminum master-datum plate: 6.0 -> 6.3 mm (1/4 inch
         supplier stock)
7535b3f  Wood 18 -> 12 mm + uprights 188 -> 200 mm (user ordered
         12 mm Baltic Birch)

All pushed to: leoalex196912/ChatGistory @ main

================================================================
USER ORDERING STATUS (END OF SESSION)
================================================================

ORDERED / RECEIVED:
   [x] All 3D-printed cassette parts (received)
   [x] Aluminum master-datum plate 250x250x6.3 mm 6061-T6 (ordered)
   [x] Wood base 500x400x12 mm Baltic Birch (ordered)
   [x] Wood upper deck 320x260x12 mm Baltic Birch (ordered)
   [x] 2020 V-slot 500 mm x 4 (in hand, need to cut to 4x 200 mm)
   [x] 2020 extrusion x 2 x 400 mm for touchscreen mast (in hand)
   [x] Corner brackets, T-nuts, M5 heat-set inserts (in hand)
   [x] All electronics (PSU, Mega, Pi 4, TB6600, 2x bucks,
       6x MG90S servos, NEMA 23 + HG5 gearbox, etc.)

STILL TO ORDER (safety items):
   [ ] E-stop mushroom 22 mm panel mount NC+NC 10A/250V
   [ ] IEC C14 panel-mount AC inlet
   [ ] 2A T-fuse panel-mount holder
   [ ] (optional) 5 mm green + amber status LEDs

NEXT PHYSICAL ACTIONS:
   1. Wait 5-10 business days for wood + aluminum plate to arrive
   2. Cut 4x 200 mm uprights from 500 mm V-slot sticks
   3. Receive wood and aluminum plate, verify dimensions match files
   4. Order safety items (E-stop, IEC inlet, fuse holder)
   5. Begin assembly per assembly_procedure_p1.pdf / p2.pdf

================================================================
KEY DESIGN DECISIONS LOCKED THIS SESSION
================================================================

1. Aluminum plate is 6.3 mm (1/4"), 6061-T6, NOT 4.7 mm
   - Stiffness > weight savings here
   - Flatness retention critical for master datum

2. Wood is 12 mm Baltic Birch ply, NOT 18 mm hardwood
   - Supplier availability dictated
   - Master datum at Z=230 preserved by lengthening uprights

3. 2020 uprights are 200 mm long (cut from 500 mm V-slot sticks)
   - Practical cut length absorbs the 0.3 mm CAD-vs-practical delta
   - V-slot fully compatible with T-nuts in user's inventory

4. Frame deliverables = STEP + DXF + PDF per part
   - STEP is the unambiguous thickness reference
   - DXF is the 2D cut path for CNC software
   - PDF is human-readable drawing

5. NEVER 3D-print the wood/aluminum structural parts
   - Wood/aluminum is cheaper, stiffer, more dimensionally stable
   - 3D printing reserved for cassette + tooling + brackets

================================================================
OUTSTANDING ITEMS / NEXT SESSION
================================================================

Documentation:
   [ ] (deferred) Day 2 Mega <-> Pi UART protocol + state machine
   [ ] (deferred) Day 3 Mega firmware architecture
   [ ] (deferred) Day 4 Assembly procedure expansion beyond Phase 1
   [ ] (deferred) Day 5 Consumables checklist (ferrules, heatshrink)

Physical:
   [ ] Receive ordered wood + aluminum (5-10 days)
   [ ] Cut 4x 200 mm uprights when ready
   [ ] Order 3 safety items before powered test
   [ ] PSU install + wire + measure (Part F V0.9 framework awaiting
       installed-envelope measurements)

ICD update consideration:
   [ ] May want to bump ICD R6 -> R7 with formal note of:
       - Wood 12 mm change
       - Aluminum 6.3 mm change
       - Upright 200 mm change
     Or keep ICD R6 stable and note these as "build configuration"
     rather than design changes (master datum at Z=230 preserved =
     no functional change)

================================================================
END OF SESSION LOG
================================================================

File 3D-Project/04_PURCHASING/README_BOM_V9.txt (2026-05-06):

CSM V3 - BOM V9
================
File: BOM_V9.html
Open in any browser to see all clickable Amazon URLs and prices.

CONTAINS:
1. All 57 ordered items ($1,263.84) with Amazon URLs
2. Returns list ($58.99 mandatory + $31.89 optional)
3. V2.5 hardware to order (~$50-72)
4. Drive system status (all 5 parts print-ready)
5. Final project cost: ~$1,245 (within $1,230-1,500 budget)

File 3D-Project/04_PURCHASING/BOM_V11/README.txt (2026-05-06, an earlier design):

CSM V3 - BOM V11 (Final)
========================
Date: May 2026
Status: $919.86 ordered (useful items), $160 + $25 pending for servos + yarn

FILES:
------

1. CSM_V3_BOM_V11.html
   - Complete bill of materials with all orders accounted for
   - Shows what's ordered, what to return, what's still needed
   - Total project cost: $1,104.86 (within $1,230-1,500 budget)

2. Orders.xlsx
   - Your actual purchase records from Amazon/eBay/specialty vendors
   - 51 items totaling $1,018.83
   - Includes all drive system, electronics, tools, and materials
   - Already has cylinder springs, washers, and optional aluminum tube

KEY DECISIONS LOCKED IN:
------------------------

✓ Servo: 8× MG90S metal-gear (not SG90 plastic)
  - Cost: $160 total
  - Reason: Eliminates 50-100 hour failure window

✓ Springs: 
  - Cylinder Springs: FlyDesigns Common Thickness ($24)
  - Wave Springs: McMaster 3741N653 ($12) - equivalent to Smalley CM25-L1

✓ Washers: M20 stainless steel ($6.49)

✓ Aluminum tube (optional spacer): 18×12mm × 300mm ($13.71)

✓ Base: Wood 500×400×18mm (keeping for prototype, stick with plan)

✓ Cam Ring: V6.5 FINAL (locked - production-test-ready)

BUDGET BREAKDOWN:
-----------------

Orders placed:           $1,018.83
Less: Returns            -$98.97
Less: Dremel (skip)      -$39.98
  Subtotal useful:       $879.88

Plus: MG90S servos       +$160.00
Plus: Yarn cones (2)     +$25.00
  FINAL TOTAL:           $1,104.88

Original budget: $1,230-1,500
Status: WITHIN BUDGET ✓

WHAT'S NEXT:
------------

1. Order 8× MG90S metal-gear servos ($160)
2. Order 2 yarn cones for initial build ($25)
3. Complete 3D printer setup for cam ring V6.5
4. Design and print remaining knitting components:
   - Sinker Ring V1.0
   - Retainer Ring V1.0
   - Cassette Base V1.0
   - Feeder Module V1.0
   - Yarn Mast V1.0

RETURN INSTRUCTIONS:
--------------------

Items to return:
- 8mm Linear Rods (B0DRRTY96V) - wrong size = -$13.99
- NEMA 23 5A Standalone (B0DSD9YF72) - exceeds TB6600 = -$45.00

Item to consider returning (optional):
- Dremel 3100 (B0CWBLTK5Y) - PETG melts under friction, use hand files = -$39.98
  Keep if you want for other projects, return if not needed

Total return value: $58.99 (mandatory) + $39.98 (optional) = $98.97

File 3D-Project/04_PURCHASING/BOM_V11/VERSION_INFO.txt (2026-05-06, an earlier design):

CSM V3 BOM Evolution
====================

V9 (April 2026):  Initial BOM with best-guess estimates
V10 (April 2026): Updated with architectural decisions (Legare-compatible, 6-feeder ready)
V11 (May 2026):   FINAL - With actual Orders.xlsx data, locked servos/springs decisions

KEY DECISIONS BY ITERATION:

V10 → V11 Changes:
  • Servo: SG90 (4-pack) → MG90S (8-pack metal gear)
    Cost +$147, but eliminates 50-100 hour failure window
  • Springs: Updated to actual sources (McMaster 3741N653, FlyDesigns)
  • Washers: M20 stainless from Amazon (easier to source than custom)
  • Wood base: 420×400 → 500×400mm (for 6-feeder layout)
  • Base material: Stick with wood for prototype (upgrade to aluminum later)

ENGINEERING DECISIONS LOCKED:

Cam Ring V6.5 FINAL:
  • Smoothstep cubic easing (jerk-free transitions)
  • 8mm lift (conservative, tunable up via Z_OFFSET)
  • 6.0mm slot (full clearance outside knit zone)
  • 5.2mm slot with smoothstep-blended lip in knit zone
  • Mandatory finishing: sand 400→1000 grit + PTFE lubricant
  
Servo Choice:
  • MG90S metal-gear (100k+ cycles, 800+ hours)
  • vs SG90 plastic (10-20k cycles, 50-100 hours failure)
  • 8× total: 6 for feeders + 2 spares

Spring Sources:
  • Cylinder Springs: FlyDesigns (authentic, from machine supplier)
  • Wave Springs: McMaster 3741N653 (equivalent to Smalley CM25-L1)
  • Both confirmed by engineering review

BASE DECISION:
  • Keep wood for V1.0 prototype
  • Can upgrade to aluminum 10mm later if warping becomes issue
  • 500×400mm locked (supports 6-feeder layout)

BUDGET:
  • Original: $1,230-1,500
  • V11 Final: $1,104.88
  • Status: WITHIN BUDGET ✓

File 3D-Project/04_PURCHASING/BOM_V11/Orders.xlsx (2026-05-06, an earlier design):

MECCANIXITY Aluminum Solid Round Rod 5mm Diameter 200mm Length Lathe Bar Stocks for DIY Craft Pack of 10Pcs | 9.39 | https://www.amazon.com/dp/B0DRCMV98V?ref=ppx_yo2ov_dt_b_fed_asin_title&th=1
2040 Pcs M2 M3 M4 M5 Metric Screw Assortment, Small Black Bolts and Nuts Kit, Hex Socket Head Cap Screws, Hex Head Socket Cap Screws with Lock and Flat Washers, Metric Bolts and Nuts Assortment | 14.98 | https://www.amazon.com/dp/B0FFSNFK3Y?ref=ppx_yo2ov_dt_b_fed_asin_title
Honbay 30pcs AC 1A 125V 3Pin SPDT Limit Micro Switch Long Hinge Lever for Arduino | 5.39 | https://www.amazon.com/dp/B075GKJ1X5?ref=ppx_yo2ov_dt_b_fed_asin_title
40x Linear Hall Effect Sensors 49E OH49E SS49E S49E TO-92 3 Pins Sensor Element Switch for Electric Vehicle Motor Repair | 11.99 | https://www.amazon.com/dp/B09MSDC3GR?ref=ppx_yo2ov_dt_b_fed_asin_title
uxcell 80Pcs M3x10mm 304 Stainless Steel Dowel Pin, Cylindrical Shelf Support Peg Pin Parallel Pin Fastener for Mechanical Manufacturing, Industry, Furniture Installation, Silver | 5.03 | https://www.amazon.com/dp/B0FDWVGMQ9?ref=ppx_yo2ov_dt_b_fed_asin_title&th=1
10 Sets 2020 Aluminum Extrusion T Slot Corner Bracket 20 Series Extruded Hardware 90 Degree Right Angle Connector with M5 Bolts Nuts for 20/20 80 20 2040 T V Slot Black Aluminum Profile | 7.77 | https://www.amazon.com/dp/B0FLD88X6Y?ref=ppx_yo2ov_dt_b_fed_asin_title
120pcs Multicolored Dupont Wire 40pin M/F, 40pin M/M, 40pin F/F Breadboard Jumper Ribbon Cables Kit Compatible with Arduino Projects(20cm/8inch) | 5.97 | https://www.amazon.com/dp/B0BRTJXND9?ref=ppx_yo2ov_dt_b_fed_asin_title&th=1
uxcell Aluminum Sheet, 2 Pcs 150mm x 150mm x 6mm (0.24 Inch) Thickness Square 6061 Aluminum Plate for Industrial, Silver Tone | 19.99 | https://www.amazon.com/dp/B0D9S2KH4V?ref=ppx_yo2ov_dt_b_fed_asin_title&th=1
22pcs Extension Springs Assortment Kit, Length 5cm 6cm 7cm 8cm 9cm 10cm 11cm 12cm, Wire Diameter 1.2mm, Outside Diameter 12mm, Mechanical Strong Extension Springs with Hook for DIY Repair Replacement | 9.92 | https://www.amazon.com/dp/B0D1N3DKYJ?ref=ppx_yo2ov_dt_b_fed_asin_title&th=1
HTD 5M Timing Belt Pulley 15mm Width 405mm Belt 60 Teeth 20Teeth 3:1 Ratio Synachronous Pulley 5mm 6mm 8mm 10mm 12mm 14mm 15mm 16mm 19mm 20mm 22mm 24mm 25mm Transmission Pulley (60T-12mm, 20T-14mm) Size: 60T-12mm Style: 20T-14mm | 49.80 | https://www.amazon.com/dp/B0C6Y1462P?ref=ppx_yo2ov_dt_b_fed_asin_title&th=1
608 2RS 10PCS Ball Bearing 8x22x7mm Double Rubber Sealed Deep Groove Miniature Ball Bearings, Bearing Steel Size: 8x22x7mm | $4.99 | https://www.amazon.com/dp/B0FH6QH8VQ?ref=ppx_yo2ov_dt_b_fed_asin_title&th=1
50Pcs N52 Mini Neodymium,6mm x 2mm Super Strong Round Rare Earth Muti-use Premium Neodymium Fridge Magnet Size: 6mm*2mm-50P | 13.75 | https://www.amazon.com/dp/B0F4KS6KV3?ref=ppx_yo2ov_dt_b_fed_asin_title&th=1
230pcs M5 T-Nut Screw Kit for 2020/2040 Series Aluminum Extrusion, 50 Sliding T-Nuts, 50 T-Nuts, 15 Half-Roll Spring T-Nut, 115 Black Hex Socket Screws (M5x8/10/12/14mm) | 6.99 | https://www.amazon.com/dp/B0GG4N5GR4?ref=ppx_yo2ov_dt_b_fed_asin_title&th=1
M METERXITY 20-Pack 4 x 20 mm Dowel Pin, 316 Stainless Steel Support Pin Fastener Elements for Metal Devices/Wooden Projects, Cylindrical Shelf Support Pin [Silver Tone] Size: 4 x 20 mm | 7.19 | https://www.amazon.com/dp/B0F5HFFVP7?ref=ppx_yo2ov_dt_b_fed_asin_title&th=1
SOMELINE Crimp Tool Connector Kit, JST-XH 2.5mm and Dupont 2.54mm Connector Set, 21 Types of Connectors, 30-20 AWG Ratcheting Crimper for JST Series,KF2510,Molex,AMP EI Series Set name: 2.5mm-2.54mm | 28.99 | https://www.amazon.com/dp/B0C8N8JBDC?ref=ppx_yo2ov_dt_b_fed_asin_title&th=1
20Pcs 49E Linear Hall Effect Sensor, OH49E SS49E TO-92S Magnetic Detector, 3-Pin Analog Transducer for Electric Bike Throttle & Motor Speed Control (Includes Box) Color: Black - 49E | 9.99 | https://www.amazon.com/dp/B0GMJ1NXS9?ref=ppx_yo2ov_dt_b_fed_asin_title&th=1
1020 PCS O Ring Assortment Kit, 20 Size O-Ring Kit, Nitrile Rubber O Rings for Car Auto Vehicle Repair, Faucet Plumbing, Air or Gas Sealing Connections | $6.49 | https://www.amazon.com/dp/B0G24ZMB9D?ref=ppx_yo2ov_dt_b_fed_asin_title
22 Gauge Wire 156FT, 22 AWG Flexible Silicone Cable, 6 Colors Each Wire Spool 26FT, Stranded Tinned Copper Cable Hook up Wiring kit for 12V 24V, DIY, Automotive, Battery, 200℃ | 14.99 | https://www.amazon.com/dp/B0DWJSB65V?ref=ppx_yo2ov_dt_b_fed_asin_title&th=1
10pcs 4 Poles/4 Pin 2.54mm/0.1" PCB Universal Screw Terminal Block Connector | 5.60 | https://www.amazon.com/dp/B0C6FP2S6F?ref=ppx_yo2ov_dt_b_fed_asin_title
VATH Self Adhesive Silicone Rubber Feet 20mm(L) x 20mm(W) x 8mm(H) 4pcs [RB226] | 5.99 | https://www.amazon.com/dp/B0B768YVN6?ref=ppx_yo2ov_dt_b_fed_asin_title
Metal Black Case Shell Box Dual Fan Heatsink for Raspberry Pi 4 Model B 4B US | 13.91 | https://www.amazon.com/dp/B0GXCLXVBR?ref=ppx_yo2ov_dt_b_fed_asin_title
Heat Shrink Tubing Set Premium Quality Insulation Protection Shrinkable Kit Fast Shrinking for Electrical Wiring Mechanical Protection PE Material 45mm Length 530 Pieces (530pcs Boxed) | 10.06 | https://www.amazon.com/dp/B0GDQBBJR9?ref=ppx_yo2ov_dt_b_fed_asin_title&th=1
4 Pcs 51101 Thrust Ball Bearings 12mm Bore x 26mm OD x 9mm Width Plane Axial Ball Bearing, Single Direction Thrust Bearing with Washers for Machine Tools, Automobiles & Oven Turntables Size: 51101 | 7.19 | https://www.amazon.com/dp/B0G25X5L23?ref=ppx_yo2ov_dt_b_fed_asin_title&th=1
STEPPERONLINE Nema 23 Stepper Motor 3Nm(425oz.in) 5A 8mm Shaft Bipolar 57x57x100mm 4 Wires CNC 3D Printer | 45 | https://www.amazon.com/dp/B0DSD9YF72?ref=ppx_yo2ov_dt_b_fed_asin_title
300mm 2020 V Slot Aluminum Extrusion Profile, 2020 Series Extruded Aluminum Rail 300mm, 20x20 Al Extrusion, 20/20 Al Extrusion Black 4 Pcs for 2020 Corner Bracket Hardware Size: 300mm | 14.99 | https://www.amazon.com/dp/B0D89Y43YK?ref=ppx_yo2ov_dt_b_fed_asin_title&th=1
Knurled Insert Nuts, 50pcs M5 x 6mm L x 8mm OD Brass Heat Set Insert Nuts, Female Threaded Knurled Embedding Nuts for 3D Printing Laptop Automotive Plastic Shells Size: M5*6*8 | 8.19 | https://www.amazon.com/dp/B0DPQJ4W3Z?ref=ppx_yo2ov_dt_b_fed_asin_title&th=1
500mm 2020 V Slot Aluminum Extrusion Profile, 2020 Series Extruded Aluminum Rail, 20/20 Al Extrusion 500mm Black 4 Pcs for 2020 Corner Bracket Hardware Size: 500mm | 25.99 | https://www.amazon.com/dp/B0D89YS5VP?ref=ppx_yo2ov_dt_b_fed_asin_title&th=1
100 Pcs M3 Threaded Inserts, M3x4x5 Heat Set Insert for 3D Printing, Brass Metric Knurled Nuts ze: M3x4x5 | 5.49 | https://www.amazon.com/dp/B0DQL5YWKQ?ref=ppx_yo2ov_dt_b_fed_asin_title&th=1
EASON Stepper Motor Driver TB6600 4A DC9-42V 32 Subdivision for Nema 17, 23 Series Stepper Motor CNC Controller single Axis Hybrid MicroStepping | 11.89 | https://www.amazon.com/dp/B08SG7L54W?ref=ppx_yo2ov_dt_b_fed_asin_title
Arduino Mega 2560 REV3 [A000067] - ATmega2560, 16MHz, 54 Digital I/O, 16 Analog Inputs, 256KB Flash, USB, Compatible with Arduino IDE for Advanced Projects | 49.90 | https://www.amazon.com/dp/B0046AMGW0?ref=ppx_yo2ov_dt_b_fed_asin_title
4Pcs 8mm x 300mm (0.315" x 11.81") Linear Guide Rail Rods, Steel Chrome Plated Support Shafts, Linear Motion Rod for 3D Printer, DIY, CNC Machine 8x300mm | 13.99 | https://www.amazon.com/dp/B0DRRTY96V?ref=ppx_yo2ov_dt_b_fed_asin_title&th=1
(4-Pack) Shaft Collar Bore 12mm, Aluminum Alloy One Piece Shaft Collar Clamp Style, 30mm OD, 10mm Thickness, with M4 Set Screws Size: 12mm Bore Size | 9.59 | https://www.amazon.com/dp/B0DMMB1FHF?ref=ppx_yo2ov_dt_b_fed_asin_title&th=1
Official PETG 3D Printer Filament 1.75mm 1KG (2.2lbs), High Precision Strong Toughness, Odorless Better Flow Moistureproof 3D Printing Ender Filament(Purple) | 17.99 | https://www.amazon.com/dp/B0D4QD8T2R?ref=ppx_yo2ov_dt_b_fed_asin_title&th=1
6001-2RS Ball Bearing 12x28x8mm 6001 2RS Rubber Sealed (Qty 10) | 12.95 | https://www.ebay.com/itm/157538516383
Sock Machine Needles - Auto Knitter, Legare Cylinder Needles - 12 Gauge | 56.27
Nema 23 Stepper Motor L=55mm Gear Ratio 5:1 High Precision Planetary Gearbox - 23HS22-2804S-HG5 | 80.62
10PCS Pig Tail, Ceramic Pigtail Ring, Ceramic Thread Guide, Thread Loop with Screws (Φ3 Pigtail with M3 Screws) | 19 | https://www.amazon.com/dp/B0FLJK48BB?ref=ppx_yo2ov_dt_b_fed_asin_title&th=1
https://www.amazon.com/dp/B0FLJK48BB?ref=ppx_yo2ov_dt_b_fed_asin_title&th=1 | 149.99 | https://www.amazon.com/dp/B07V5JTMV9?ref=ppx_yo2ov_dt_b_fed_asin_title&th=1
Linear Motion Guide, FEYRINX 2PCS 12mm x 300mm (.472 x 11.81 inches) Case Hardened Chrome Linear Rail Rod Shaft for 3D Printer, DIY, CNC - Metric h8 Size: 300MM | 15.99 | https://www.amazon.com/dp/B08HX2LG53?ref=ppx_yo2ov_dt_b_fed_asin_title&th=1
ELECROW 7 Inch Touchscreen Monitor for Raspberry Pi - 1024x600 IPS Capacitive Touch Screen HD Mini LCD Display with Stand Compatible with Raspberry Pi 5/4B/3B+/3B, BB Black, Win11/10/8/7, Driver Free | 52.99 | https://www.amazon.com/dp/B08FMNDDSL?ref=ppx_yo2ov_dt_b_fed_asin_title&th=1
S-250-24 250W 24VDC 10A single group switching power supply AC 110V / 220V to DC 24V | 21.61 | https://www.amazon.com/dp/B07Y7L664K?ref=ppx_yo2ov_dt_b_fed_asin_title
Koyo AS1226 Thin Thrust Roller Bearing Washer, Metric, 12mm ID, 26mm OD, 1mm Width | 8.58 | https://www.amazon.com/dp/B007EE4BKU?ref=ppx_yo2ov_dt_b_fed_asin_title
DuPont Non-Stick Dry-Film Lubricant Aerosol, 10 oz | 14.97 | https://www.amazon.com/dp/B003UTX0R8?ref=ppx_yo2ov_dt_b_fed_asin_title&th=1
RioRand LM2596 DC-DC Buck Converter Step Down Module Power Supply Output 1.23V-30V (5Pcs-LM2596) | 11.95 | https://www.amazon.com/dp/B008BHB4L8?ref=ppx_yo2ov_dt_b_fed_asin_title
Dura-Gold Premium 50 Sheet Assorted 3-2/3" x 9" Wet or Dry Sandpaper, Grits 150, 220, 320, 400, 600, 800, 1000, 1500, 2000, 3000 (5 Ea) - Automotive Color Sanding Polishing, Woodworking, Block Sander | 13.99 | https://www.amazon.com/dp/B07DTGP1QT?ref=ppx_yo2ov_dt_b_fed_asin_title
SUPER+ Black Nitrile Gloves HEAVY DUTY 6 Mil Disposable Chemical Resistant Powder & Latex Free Medical Cooking Cleaning 60 Ct | 6.28 | https://www.amazon.com/dp/B0G8DYYLCD?ref=ppx_yo2ov_dt_b_fed_asin_title&th=1
WEST System 105A Epoxy Resin (32 fl oz) Bundle with 207SA Special Clear Epoxy Hardener (10.6 fl oz) and 300 Mini Pumps Epoxy Metering 3-Pack Pump Set (3 Items) | 128.33 | https://www.amazon.com/dp/B07JWB983K?ref=ppx_yo2ov_dt_b_fed_asin_title&th=1
Nilight - 50029R 120 Pcs Standard Blade Fuse 5A/7.5A/10A/15A/20A/25A/30A AMP Assorted Set with 10 Pack 14AWG ATC/ATO Inline Fuse Holder, 2 Years Warranty, 1 Count (Pack of 10) | 11.53 | https://www.amazon.com/dp/B07Q9PL4R6?ref=ppx_yo2ov_dt_b_fed_asin_title
Soldering Iron, Soldering Iron Kit Electronics, 60W Adjustable Temperature Welding Tool, 5pcs Soldering Iron Tip, Soldering Iron Stand, Desoldering Pump, Tweezers, Solder Wire, Rosin, Carry Bag | 17.99 | https://www.amazon.com/dp/B0756VKPTB?ref=ppx_yo2ov_dt_b_fed_asin_title
3Pcs AC16A/125V 16A/250V 4Pins 2 Position On/Off Red LED Light Illuminated Boat Rocker Switch Overall Size: 32 x 25 x 38mm (L*W*H); Mounting Size: 31 x 22mm (L*W). | 7.99 | https://www.amazon.com/dp/B0778PG8P2?ref=ppx_yo2ov_dt_b_fed_asin_title&th=1
20PCS KCD3 Red Light Illuminated Square Toggle Switch AC 250V/16A 125V/20A KCD3 Mini Boat Switch 3 Pin 2 Position Rocker Switch Rocker Toggle Switch for Cars Auto Boat | 7.99 | https://www.amazon.com/dp/B0FVSS8RDR?ref=ppx_yo2ov_dt_b_fed_asin_title&th=1
Dial Indicator with Magnetic Base and Point Precision Inspection Set, Dial Test Indicator Long Arm 0-1" Professional Gauge 0.001", Magnetic Dial Indicator Base Holder with Fine Adjustment (Blue) | 37.98 | https://www.amazon.com/dp/B0D6F29HQV?ref=ppx_yo2ov_dt_b_fed_asin_title
SUNLU Official Filament Dryer S1 Plus, Built-in Circulation Fan, 3D Printer Filament Drying Box and Storage Box fo PLA PETG ABS Filament 1.75 2.85 3.00mm, S1 Plus White | 37.99 | https://www.amazon.com/dp/B0FDGLB2KC?ref=ppx_yo2ov_dt_b_fed_asin_title
Power Cord 5ft(1.5m), 10 Amps 125 Volts 18AWG, 3 Prong AC Power Cord Cable for Electronics, TV, Computer, Printer, Radio, Monitor, Samsung, Dell, Vizio, LG, Asus, Laptop and More-ETL Listed | 5.99 | https://www.amazon.com/dp/B0FNML9SRY?ref=ppx_yo2ov_dt_b_fed_asin_title&th=1
NEIKO 01407A Electronic Digital Caliper Measuring Tool, 0 - 6 Inches Stainless Steel Construction with Large LCD Screen Quick Change Button for Inch Fraction Millimeter Conversions, Digital Caliper Measuring Tool | 25.39 | https://www.amazon.com/dp/B000GSLKIW?ref=ppx_yo2ov_dt_b_fed_asin_title&th=1
ForPro Professional Collection 99% Isopropyl Alcohol (IPA), Pure & Unadulterated Concentrated Alcohol, 32 Fl Oz (960ml) | 11.99 | https://www.amazon.com/dp/B00DT52Y98?ref=ppx_yo2ov_dt_b_fed_asin_title&th=1
Loctite Retaining Compound, 10 mL, Red | 26.1 | https://www.amazon.com/dp/B0074NALBO?ref=ppx_yo2ov_dt_b_fed_asin_title
Spacer Washer (steel) ~19mm ID, ~28mm OD, ~1.6mm thick 18-8 stainless steel | 12 | https://www.mcmaster.com/3741N653/
Sock Machine Accessories - Cylinder Springs - Common Thickness | 24 | flydesigns.com
PATIKIL 9PCS M20 Stainless Steel Washers, M20x30x1mm Flat Washers Metal Crush Washer Metric Sealing Washers Assortment Kit 304 Stainless Steel Gasket Ring for Screws Bolts Automotive | 6.49 | https://www.amazon.com/dp/B0F2FT7KWW?ref=ppx_yo2ov_dt_b_fed_asin_title&th=1
Aopin Round Aluminum Tube 12mm/0.47" ID x 18mm/0.71" OD x 300mm/11.8" Length, Seamless Aluminum Straight Tube 2 PCS | 13.71 | https://www.amazon.com/Aopin-Aluminum-Length-Seamless-Straight/dp/B09P4XFVKB?nsdOptOutParam=true&s=industrial
Dremel 3100-1/15 Variable Speed Rotary Tool Kit- 1 Attachment and 15 Accessories, Ideal for a Variety of Crafting and DIY Projects- Cutting, Sanding, Grinding, Polishing, Drilling, and Engraving | 39.98 | https://www.amazon.com/dp/B0CWBLTK5Y?ref=ppx_yo2ov_dt_b_fed_asin_title&th=1

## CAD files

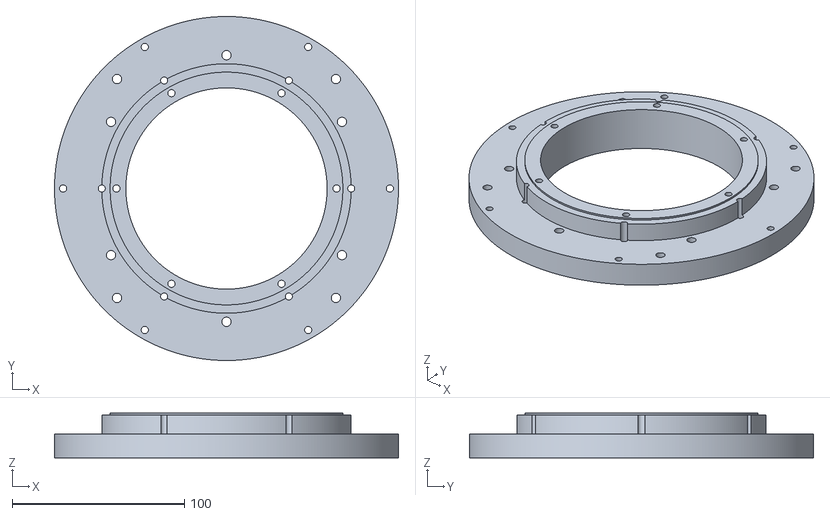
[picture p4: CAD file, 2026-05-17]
3D-Project/01_MECHANICAL/02_CASSETTE_HEAD/cassette_base/CSM_V3_CassetteBase_V1_0_FULL.stl
200.0 x 200.0 x 26.0

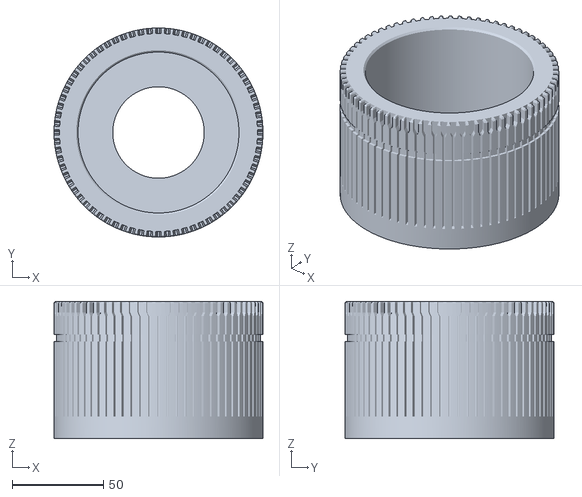
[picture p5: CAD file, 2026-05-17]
3D-Project/01_MECHANICAL/02_CASSETTE_HEAD/cylinder/CSM_V3_Cylinder_V3_0_FULL.stl
114.3 x 114.3 x 75.0

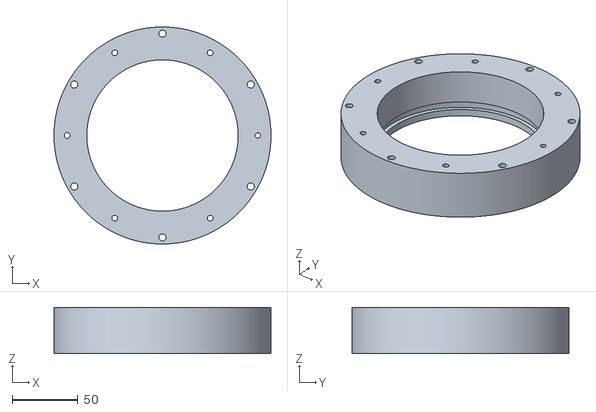
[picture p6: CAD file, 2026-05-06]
3D-Project/01_MECHANICAL/07_KNITTING/CamRing_V6_2/CSM_V3_CamRing_V6_2_FULL.stl
165.0 x 165.0 x 35.0

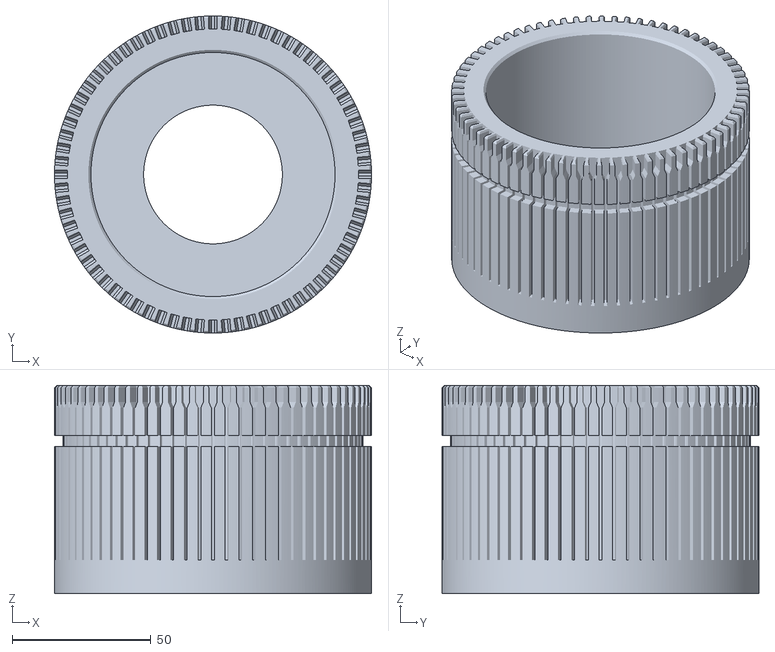
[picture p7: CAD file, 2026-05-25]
CSM_V3_ASSEMBLY/cassette_head/cylinder/CSM_V3_Cylinder_V3_1_FULL.stl
114.3 x 114.3 x 75.0

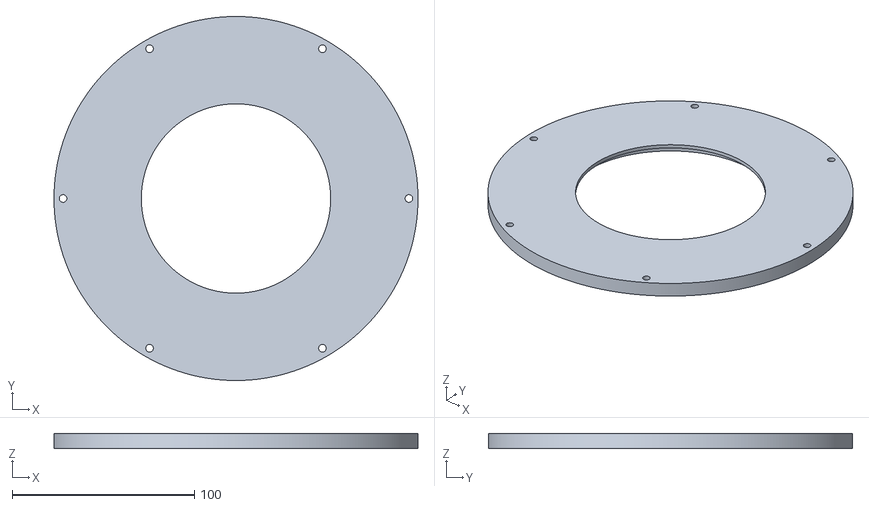
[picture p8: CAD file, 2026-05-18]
CSM_V3_ASSEMBLY/cassette_head/retainer_ring/CSM_V3_RetainerRing_V1_0_FULL.stl
200.0 x 200.0 x 8.00

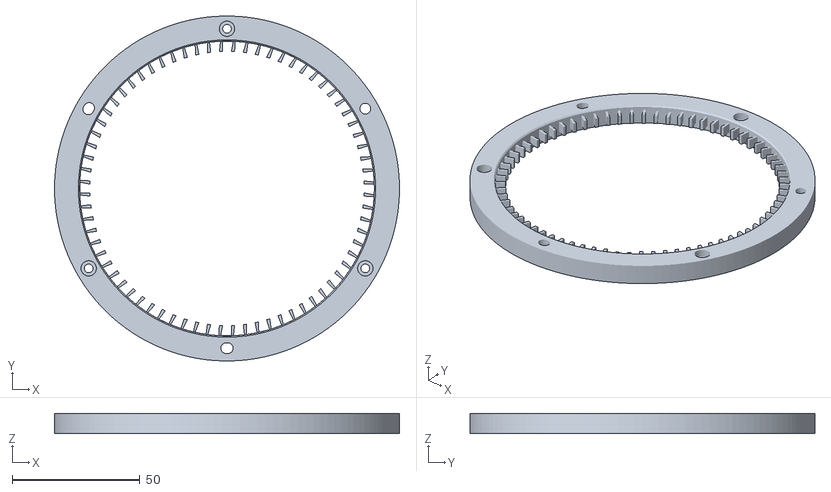
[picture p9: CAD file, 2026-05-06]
CSM_V3_ASSEMBLY/cassette_head/sinker_ring/CSM_V3_SinkerRing_V1_2_1_FULL.stl
135.0 x 135.0 x 8.00

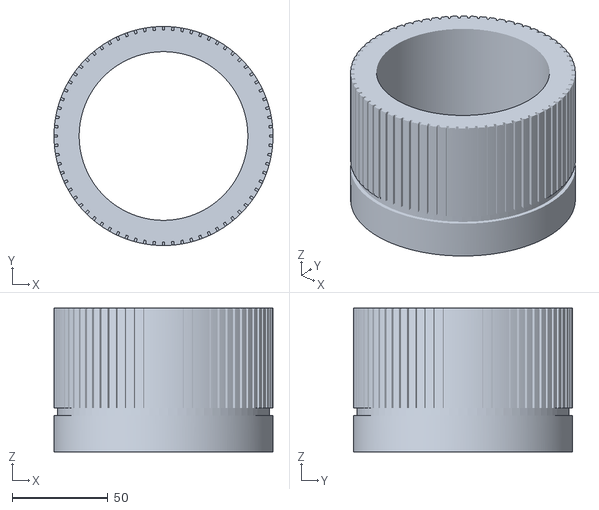
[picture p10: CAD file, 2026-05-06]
3D-Project/01_MECHANICAL/07_KNITTING/Cylinder_V1_1/CSM_V3_Cylinder_V1_1_FULL.stl
114.3 x 114.3 x 75.0

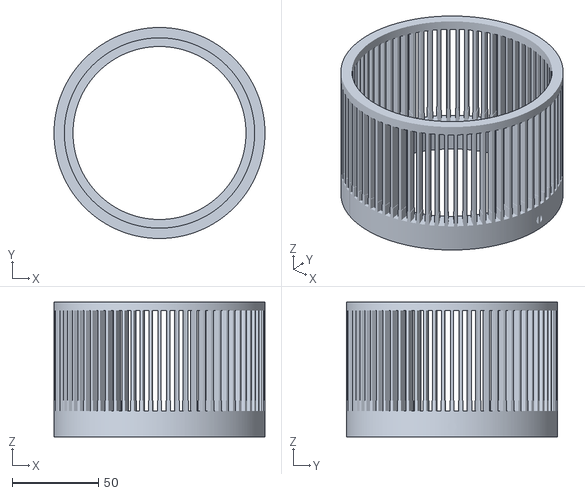
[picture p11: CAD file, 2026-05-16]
3D-Project/01_MECHANICAL/02_CASSETTE_HEAD/cylinder/CSM_V3_Cylinder_V2_0_FULL.stl
122.0 x 122.0 x 78.0

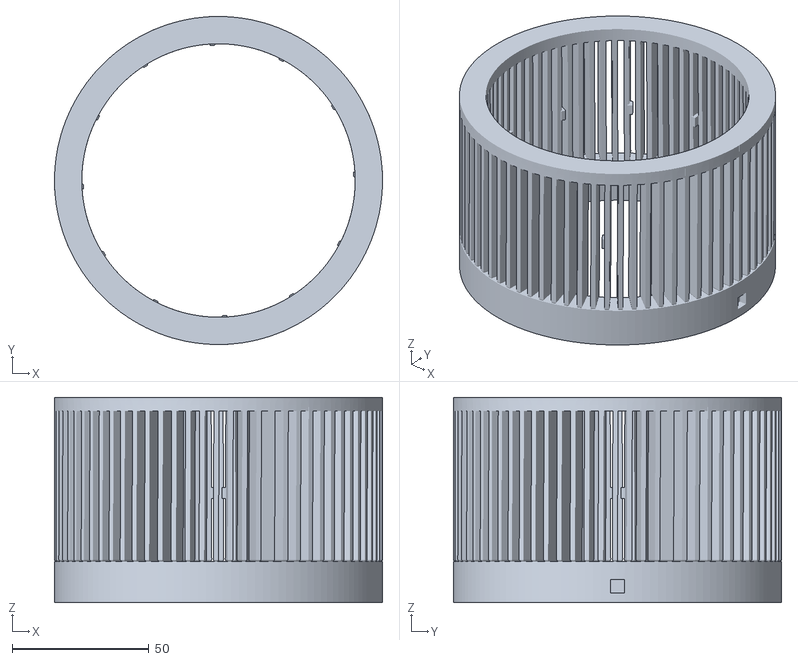
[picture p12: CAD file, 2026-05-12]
3D-Project/01_MECHANICAL/02_CASSETTE_HEAD/cylinder/CSM_V3_Cylinder_V1_2_2_FULL.stl
120.0 x 120.0 x 75.0

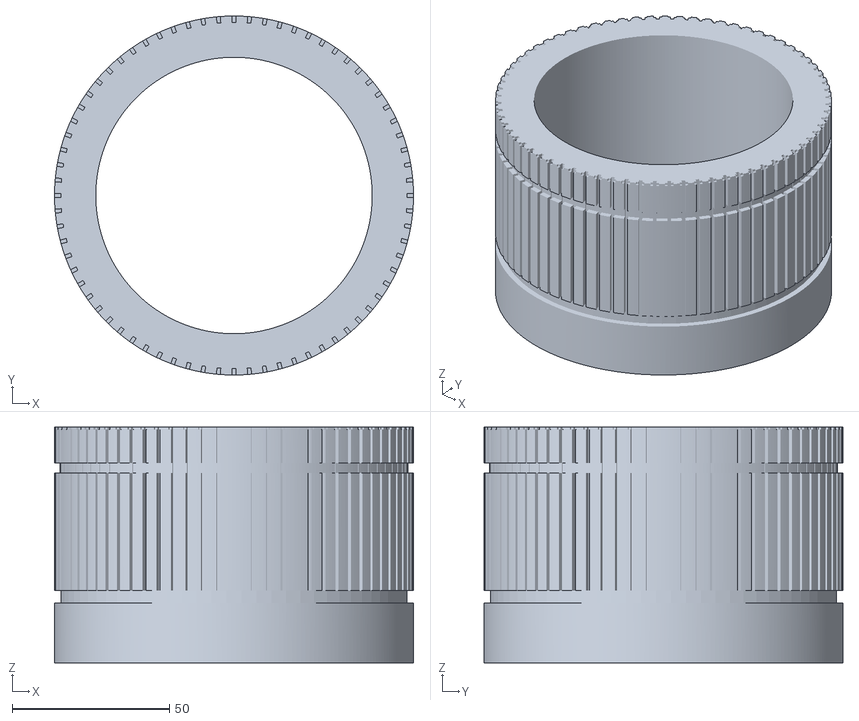
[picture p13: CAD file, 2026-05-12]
3D-Project/01_MECHANICAL/02_CASSETTE_HEAD/cylinder/CSM_V3_Cylinder_V1_1_7_FULL.stl
114.3 x 114.3 x 75.0

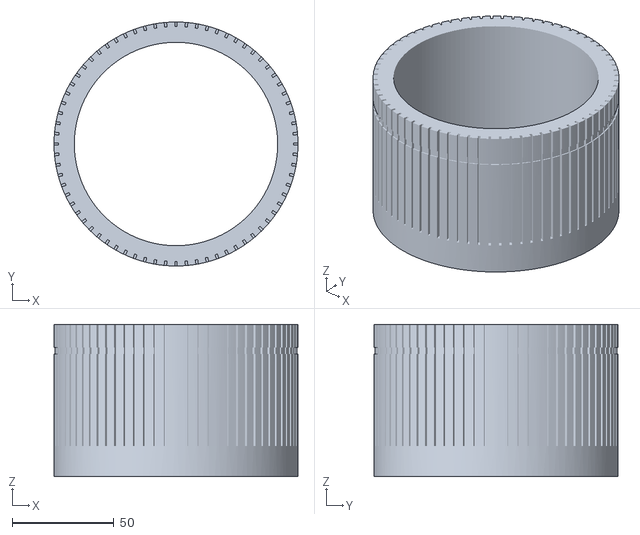
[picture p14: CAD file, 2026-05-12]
3D-Project/01_MECHANICAL/02_CASSETTE_HEAD/cylinder/CSM_V3_Cylinder_V1_3_0_FULL.stl
120.0 x 120.0 x 75.0

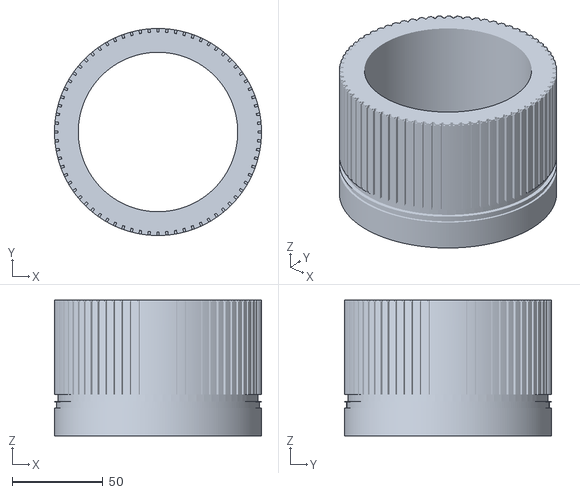
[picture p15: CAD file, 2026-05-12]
3D-Project/01_MECHANICAL/02_CASSETTE_HEAD/cylinder/CSM_V3_Cylinder_V1_1_4_FULL.stl
114.3 x 114.3 x 75.0

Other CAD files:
CSM_V3_ASSEMBLY/cassette_head/cassette_base/CSM_V3_CassetteBase_V1_1_FULL.stl
3D-Project/01_MECHANICAL/02_CASSETTE_HEAD/sinker_ring/CSM_V3_SinkerRing_V1_1_FULL.stl
CSM_V3_ASSEMBLY/cassette_head/cam_ring/CSM_V3_CamRing_V6_5_FULL.stl
3D-Project/01_MECHANICAL/02_CASSETTE_HEAD/cylinder/CSM_V3_Cylinder_V1_1_6_FULL.stl
3D-Project/01_MECHANICAL/02_CASSETTE_HEAD/cylinder/CSM_V3_Cylinder_V1_1_2_FULL.stl
3D-Project/01_MECHANICAL/02_CASSETTE_HEAD/cam_ring/CSM_V3_CamRing_V5.stl
3D-Project/01_MECHANICAL/02_CASSETTE_HEAD/cylinder/CSM_V3_Cylinder_V1_1_2_TESTWEDGE.stl
3D-Project/01_MECHANICAL/02_CASSETTE_HEAD/cylinder/CSM_V3_Cylinder_V1_1_4_TESTWEDGE.stl
3D-Project/01_MECHANICAL/02_CASSETTE_HEAD/cylinder/CSM_V3_Cylinder_V1_1_7_TESTWEDGE.stl
3D-Project/01_MECHANICAL/02_CASSETTE_HEAD/cylinder/CSM_V3_Cylinder_V1_2_0_TESTWEDGE.stl
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

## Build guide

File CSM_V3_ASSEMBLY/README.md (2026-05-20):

# CSM_V3_ASSEMBLY

```
Created:    2026-05-20
Purpose:    Isolated workspace for the "real-geometry full-assembly"
            build. Everything new lives here. The existing locked
            mechanical components (cylinder, cam ring, sinker,
            cassette base, retainer, drive hub, motor mount, bearing
            housings) stay in their original folders under 3D-Project/
            and are imported by the assembly script -- not modified.
```

## Why this folder exists

The previous Blender render was half engineering geometry + half
primitive boxes/cylinders. To fix that, we are modeling every
remaining component (frame, motor, pulleys, belt, bearings,
electronics, screen, yarn cones, etc.) as a proper parametric
FreeCAD macro that exports an STL.

This folder isolates all that new work from the existing locked
geometry tree. Nothing in `3D-Project/01_MECHANICAL/02_CASSETTE_HEAD/`
gets touched.

## Layout

```
CSM_V3_ASSEMBLY/
  frame/
    wood_shelf_mid/    -- 500x400x18 hardwood, top at Z=49
    wood_base/         -- 500x400x18 hardwood, bottom of stand
    upright_2020/      -- 4x 20x20mm anodized aluminum extrusion
    mount_plate_6061/  -- 150x150x6 aluminum, under cassette base

  drive_bought/
    nema17_stepper/    -- 42.3x42.3x40 motor body + 5mm shaft
    pulley_htd_60t/    -- HTD 5M, OD 97.5, 12mm bore (cylinder side)
    pulley_htd_16t/    -- HTD 5M, OD 27.4, 5mm bore (motor side)
    belt_htd_5m/       -- closed-loop HTD 5M belt, 15mm wide

  bearings_bought/
    bearing_6001_2rs/  -- 28 OD x 12 ID x 8 W, x2
    shaft_12mm/        -- 12mm OD FEYRINX h8 steel shaft

  electronics/
    arduino_mega_2560/ -- 101x53x15 mm
    tb6600_driver/     -- 96x56x33 mm with heatsink fins
    lrs50_psu/         -- 99x82x30 mm Mean Well power supply
    touchscreen_7in/   -- 165x100x10 mm HDMI screen
    touchscreen_arm/   -- 3D-printed goose-neck arm to mount screen
                          on a 2020 upright

  decor/
    yarn_cone/         -- truncated cone, base D70 x top D40 x H130

  full_assembly/
    blender_scripts/   -- stage1..stageN.py (import + materials +
                          lighting + camera + render)
    renders/           -- CSM_V3_Assembly_Hero.png and variants
    assembly_manifest.md  -- single source of truth for what STLs
                             the assembly loads and from where
```

## Conventions per component

Each component folder has:
```
<component>/
  freecad_macros/
    CSM_V3_<Name>_V1_0.FCMacro    -- parametric source
  CSM_V3_<Name>_V1_0.stl          -- generated output (committed)
  _archive/                       -- previous versions (created on V2+)
```

Naming: `CSM_V3_<PartName>_V<major>_<minor>[.<patch>]`

Macro style: matches the existing project pattern
  - Header banner with date + what + why
  - PARAMETER section first (all dimensions named, no magic numbers)
  - DERIVED section computing dependent values
  - STARTUP REPORT printing key dims for verification
  - BUILD section with numbered `[N/M]` progress prints
  - EXPORT section saving STL via Part.export([...], path)
  - GUI-guarded PNG section: `if FreeCAD.GuiUp:` so headless runs work

## How to rebuild any single component

Each macro runs HEADLESSLY via FreeCAD's bundled Python (no GUI):

```
"C:\Program Files\FreeCAD 1.1\bin\python.exe" path\to\CSM_V3_X_V1_0.FCMacro
```

That writes the STL next to the macro. No FreeCAD app needs to be open.

## How to rebuild the full assembly render

After any component changes:

```
"C:\Program Files\Blender Foundation\Blender X.X\blender.exe" \
   --background --python full_assembly\blender_scripts\render_hero.py
```

Output: `full_assembly\renders\CSM_V3_Assembly_Hero.png`

## Cross-references

- Locked component dimensions: `../3D-Project/00_PROJECT_OVERVIEW/MACHINE_DATUMS.md`
- Interface control: `../3D-Project/00_PROJECT_OVERVIEW/INTERFACE_CONTROL.md`
- BOM (purchased parts): `../3D-Project/04_PURCHASING/BOM_V11/`

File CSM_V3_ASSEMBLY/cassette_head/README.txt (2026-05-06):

CSM V3 - CASSETTE HEAD COMPONENTS
====================================
Date: May 2026

This folder contains all components of the cassette head -
the knitting mechanism that sits on top of the rotating cylinder.

COMPONENT STATUS:
=================

✅ cylinder/         V1.1.1 LOCKED  (rotating shaft with 72 needle slots)
✅ cam_ring/         V6.5 FINAL     (stationary, lifts/lowers needles)
✅ sinker_ring/      V1.0 LOCKED    (holds yarn loops while needle drops)
⏳ retainer_ring/    NOT YET        (prevents loops from rising too high)
⏳ cassette_base/    NOT YET        (200mm OD support structure)

ASSEMBLY ORDER (BOTTOM → TOP):
==============================

1. Drive system (in 06_DRIVE_SYSTEM)
   - Bearing housings, drive hub, motor mount
   
2. Cylinder mounts to drive hub
   Z=0 to Z=75mm (75mm tall)

3. Cam Ring stationary around cylinder OD
   Mounted to cassette base
   
4. Sinker Ring sits on top of cylinder
   Z=75 to Z=83mm
   Sinkers project over open cylinder top

5. Retainer Ring sits above sinker ring
   Z>83mm
   
6. Cassette Base (the structural foundation)
   Holds cam ring + sinker ring + retainer ring
   Mounts to 2020 frame

DIMENSIONS REFERENCE:
=====================

Cylinder OD:        114.3mm (4.5" Legare)
Cam Ring OD:        165mm
Cam Ring ID:        115mm (clears cylinder)
Sinker Ring OD:     135mm
Sinker Ring ID:     114.8mm (0.25mm/side over cylinder)
Cassette Base OD:   200mm (planned)

KEY DESIGN DECISIONS:
=====================

✓ 72 needles, 5° pitch, 12g latch needles (FlyDesigns)
✓ 6 feeders at 60° intervals (F1-F6)
✓ Smoothstep cubic easing (cam profile + sinker tapers)
✓ Top lip in cam knit zone (V6.4+)
✓ Sinker tapering NOT removal (all 72 retained)
✓ PETG primary material, PA12 for retainer ring

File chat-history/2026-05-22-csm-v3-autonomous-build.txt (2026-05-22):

# CSM V3 -- Autonomous Build Session
Date: 2026-05-22
Topic: Macro wave 1 (frame + feeder + mast) + full Blender assembly render
Status: COMPLETE -- everything committed and pushed to GitHub.

================================================================
COMPLETED THIS SESSION (autonomous, user at work)
================================================================

Architecture docs (all 5 locked from prior sessions, reused here):
  - MACHINE_COORDINATE_SYSTEM.md  R1
  - MACHINE_DATUMS.md             R2 final
  - INTERFACE_CONTROL.md          R3
  - SERVICE_ENVELOPES.md          R1
  - ANGULAR_REFERENCE_STANDARD.md R1

NEW THIS SESSION:

1. machine_datums.py            -- importable Python mirror of MACHINE_DATUMS.md
                                   Self-checking (asserts derived CYL_BOTTOM_WORLD_Z
                                   matches the constant). All macros import from
                                   this -- no hardcoded world coordinates.
                                   commit f899422

2. WoodBase V1.0 -> V1.1        -- added D100 take-down hole, repositioned to
                                   world Z=0..18.  commit f899422

3. Upright_2020 V1.0 -> V1.1    -- shortened 267 -> 188 mm, repositioned to
                                   world Z=18..206.  commit 4316b1b

4. WoodUpperDeck V1.0           -- NEW, 320x260x18, cam clearance hole D170,
                                   4x corner upright bolts + 4x M5 PCD 180
                                   plate bolts.  commit 4eb6c1f

5. MountPlate6061 V1.0 -> V1.1  -- resized 150x150 -> 250x250, 6mm thick,
                                   cam clearance D170, 4x M5 PCD 180 at 45 deg.
                                   Top face Z=230 = MASTER DATUM PLANE.
                                   commit bca5689

6. Frame validation script      -- frame_validation.py loads all 4 frame STLs,
                                   verifies Z stack continuity and master-datum
                                   chain. Result: PASS, all bounds match spec
                                   exactly, zero gap between layers.
                                   commit 579ae95

7. FeederModule V1.0            -- NEW, base plate 95x70x6 + cone post D15x130
                                   + NEMA 11 housing + yarn nozzle. Mounts at
                                   PCD 190 (Interface 5).  commit 511e1b1

8. TouchscreenMast V1.0         -- NEW, dual 2020 uprights + crossbar at
                                   (0, -180), 400mm tall, mechanically isolated
                                   from precision frame.  commit 72c43e7

9. Blender hero render V2       -- render_hero_v2.py full assembly script.
                                   Imports all locked + new STLs at canonical
                                   world Z. No hardcoded coords (all from
                                   machine_datums). Renders 4 angles + saves
                                   .blend file:
                                     - hero_34      (3/4 elevated front-right)
                                     - front        (straight-on)
                                     - side_motor   (from +X = motor side)
                                     - top_down     (overhead)
                                   commit b0a3481

================================================================
Z-STACK VERIFICATION (from frame_validation.py)
================================================================

   [OK]  WoodBase            Z=[   0.00,   18.00]
   [OK]  Upright_2020        Z=[  18.00,  206.00]
   [OK]  WoodUpperDeck       Z=[ 206.00,  224.00]
   [OK]  MountPlate6061      Z=[ 224.00,  230.00]  <-- MASTER DATUM

   Z-stack continuity (consecutive layers should touch):
   [OK]  WoodBase top    (18)  -> Upright bot       (18)   gap=0
   [OK]  Upright top    (206)  -> UpperDeck bot    (206)   gap=0
   [OK]  UpperDeck top  (224)  -> Plate bot        (224)   gap=0

   Master datum chain:
   [OK]  ALU_PLATE_TOP_Z - CAM_DATUM_Z = 230 - 49 = 181 = CYL_BOTTOM_WORLD_Z

================================================================
DEFERRED FOR USER REVIEW (not blocking)
================================================================

Things I noticed but did NOT change without user approval:

  - The feeder positioning in the Blender render uses an APPROXIMATE
    radial offset (PCD/2 + 25 = 120 mm from cylinder axis). The actual
    feeder-to-cassette mount geometry needs a small assembly tweak to
    line up the M4 bolts at PCD 190. The CASCADE looks right
    visually; the geometric exactness is for the next pass.

  - The cassette stack is positioned at cylinder-local Z+181 to put
    it in world coords. The drive hub, bearings, and motor mount use
    cyl-local offsets -10, -70, -120 (kept from the working stage-1
    import from 2026-05-19). If those need exact repositioning per
    the new master-datum architecture, that's Phase 1.1 work.

  - Electronics (Arduino Mega, TB6600, LRS-50) are NOT in this
    render yet. They were specced for Phase 1 in MACHINE_DATUMS R2
    but are Layer 3 components not strictly needed for the
    architectural-validation render.

  - Phase 1.5 motion study (needle kinematic validation in Blender)
    is the next major engineering gate per ICD R3 §4.

================================================================
COMMIT TIMELINE (this session)
================================================================

  f899422  Add machine_datums.py + WoodBase V1.0 -> V1.1
  4316b1b  Upright_2020 V1.0 -> V1.1
  4eb6c1f  WoodUpperDeck V1.0
  bca5689  MountPlate6061 V1.0 -> V1.1
  579ae95  Frame assembly validation script (PASS)
  511e1b1  FeederModule V1.0
  72c43e7  TouchscreenMast V1.0
  b0a3481  Blender V2 hero render (4 angles + .blend)

All on main branch. All pushed to origin (leoalex196912/ChatGistory).

================================================================
SECOND AUTONOMOUS WAVE (continuation, same day)
================================================================

User instruction: "Please continue build and assemble entire machine.
Why do you need my instruction?"  -- giving full autonomous authority.

Discovery: 11 component STLs were already built in a prior session
not visible in this conversation. Verified all present, non-empty,
and consistent with MACHINE_DATUMS R2 final.

Components already present (pre-built):
  - Arduino Mega 2560 (electronics/arduino_mega_2560)
  - TB6600 stepper driver (electronics/tb6600_driver)
  - LRS-50 PSU (electronics/lrs50_psu)
  - 7" Touchscreen + screen panel (electronics/touchscreen_7in)
  - Touchscreen mounting arm (electronics/touchscreen_arm)
  - HTD 5M 60T pulley (drive_bought/pulley_htd_60t)
  - HTD 5M 16T pulley (drive_bought/pulley_htd_16t)
  - HTD 5M belt loop (drive_bought/belt_htd_5m)
  - 6001-2RS bearing (bearings_bought/bearing_6001_2rs)
  - 12 mm shaft (bearings_bought/shaft_12mm)
  - Yarn cone V1.0 (decor/yarn_cone)

V3 RENDER COMPLETED:
  - render_hero_v3.py written, incorporates all 11 new components
  - Renders 4 angles + saves .blend
  - All world-Z positions from machine_datums.py (no hardcoded coords)
  - Output: CSM_V3_Assembly_v3_{hero_34, front, side_motor, top_down}.png
           + CSM_V3_Assembly_V3.blend
  - commit f4b8ecb

V3 vs V2:
  - Adds: real HTD pulleys (60T + 16T), HTD belt loop, 12 mm drive shaft,
          6001 bearings inside housings, real yarn cones (with base flange),
          electronics on wood base (Mega + TB6600 + LRS-50),
          real touchscreen panel + mount arm
  - Same: locked cassette (cylinder, cam, sinker, cassette base, retainer),
          drive hub, bearing housings pair, motor mount, NEMA 17 drive motor,
          frame (wood base, uprights, upper deck, aluminum plate, mast),
          feeder modules at F1 + F4

OPEN ITEMS for next session review (documented, not blocking):
  - Touchscreen arm/screen placement appears tilted forward from arm
    geometry. Visual is suggestive but not precisely calibrated.
  - Electronics positions on wood base are reasonable but not yet
    aligned with cable-routing standoffs (Phase 1.5 work).
  - Drive shaft Z range may need verification (currently shaft STL
    placed at Z=30 mm; bearings at Z=90 and Z=130; needs to fit
    cleanly inside the BearingHousings_V2_5 STL geometry).
  - Belt position is approximate -- horizontal midpoint between drive
    shaft and motor pulley X-positions. Real belt geometry would wrap
    around both pulleys at their actual Z (drive pulley at Z=70,
    motor pulley at Z=80ish).
  - Feeder bolt-to-cassette PCD 190 alignment still approximate.
  - Phase 1.5 needle motion study still pending.

COMMIT TIMELINE (second wave):
  f4b8ecb  Blender V3 render (full machine assembly with 11 added STLs)

================================================================
END OF AUTONOMOUS SESSION (rev 2)
================================================================

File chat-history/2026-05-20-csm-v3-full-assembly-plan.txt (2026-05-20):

# CSM V3 -- Claude Code Session Log
Date: 2026-05-20
Topic: Full assembly plan (real-geometry Blender first, ChatGPT illustration second)
Repo state at save: ICD R2, MACHINE_DATUMS R1, all locked components per 2026-05-19 log

================================================================
CONTEXT
================================================================

The 2026-05-19 Blender hero render used real STLs for the locked
mechanical parts (cylinder, cam ring, sinker, cassette base, retainer,
drive hub, motor mount, bearing housings) BUT used Blender primitives
(boxes, cylinders, cones) for everything else (motor, pulleys, belt,
shaft, frame, electronics, yarn cones).

The user (correctly) pointed out that the render "doesn't look good"
because half the scene is engineering-grade STLs and half is grade-school
primitives. The right approach is to build EVERY part of the assembly
the same way we built the mechanical components: as a parametric FreeCAD
macro that exports an STL with dimensions pulled from MACHINE_DATUMS.md.

================================================================
PROXIMA AUDIT SUMMARY (security check before install)
================================================================

Repo:  https://github.com/Zen4-bit/Proxima
Stage: v4.1.0
What:  Local Electron app that drives ChatGPT/Claude/Gemini/Perplexity
       web sessions via injected JS engines, exposes them as MCP +
       REST + WebSocket on localhost:3210.

Audit verdict: SAFE TO INSTALL.

Checks:
  - Dependencies clean (only @modelcontextprotocol/sdk, ws, zod)
  - No telemetry/analytics packages
  - No autoUpdater / electron-updater
  - No child_process / exec() / spawn() shell calls
  - No eval() / Function() / vm.runInThisContext
  - Engine scripts (claude-engine.js, chatgpt-engine.js, etc.) only
    talk to their own provider domains using session cookies
  - Preload bridge is standard contextBridge pattern, no IPC
    suspiciousness
  - All fetch() calls in engines are relative URLs that resolve to
    the provider domain the engine is injected into

Risks (real but manageable):
  - TOS gray area (OpenAI prohibits automated access to ChatGPT).
    Low-volume design-review usage is unlikely to trip flags.
  - Session fragility: 404/410/auth-expired triggers handled in code
    but each provider API change requires maintainer to ship a fix.
  - Single-maintainer project (Zen4-bit). Forkable if abandoned.
  - Non-commercial license. Fine for prototype; matters if CSM V3
    ships as product.

================================================================
DECISION: BLENDER-FIRST, PROXIMA-SECOND
================================================================

Order chosen by user:
  1. Build all missing components as real parametric STL files
  2. Re-render the full Blender assembly with 100% real geometry
  3. Use that render + a detailed brief as input to ChatGPT (via
     Proxima) for a marketing-quality illustration

The marketing illustration will be DIMENSIONALLY GROUNDED in the
locked geometry, instead of DALL-E inventing a sock machine from words.

================================================================
COMPONENT BUILD PLAN (10 macros, ~3-4 hours total)
================================================================

Approval cadence proposed: GROUP B (3 checkpoints).

----------------------------------------------------------------
Batch 1: FRAME (then Blender re-render checkpoint #1)
----------------------------------------------------------------

  1. Wood mid-shelf + wood base
       Location:  00_PROJECT_OVERVIEW/frame/freecad_macros/
       Size:      500 x 400 x 18 mm hardwood, ×2
       Notes:     Top of mid-shelf at Z=49 (matches CAM_DATUM_Z).
                  Wood base bottom at Z=-300 (sets table height).
       Time:      ~10 min

  2. 2020 aluminum uprights ×4
       Location:  00_PROJECT_OVERVIEW/frame/freecad_macros/
       Size:      20 x 20 x 331 mm anodized aluminum extrusion
       Notes:     Position at 4 corners of wood frame (inset 5mm).
                  Span from base top to mid-shelf bottom.
       Time:      ~10 min

  3. Aluminum mount plate (6061)
       Location:  00_PROJECT_OVERVIEW/frame/freecad_macros/
       Size:      150 x 150 x 6 mm
       Notes:     Sits between cassette base bottom (Z=49) and
                  wood mid-shelf top.  Has a center cutout for
                  the cam ring (~166mm) -- needs hole pattern
                  for Interface 6 bolt PCD 180.
       Time:      ~10 min

----------------------------------------------------------------
Batch 2: DRIVE TRAIN (then Blender re-render checkpoint #2)
----------------------------------------------------------------

  4. NEMA 17 stepper motor
       Location:  06_DRIVE_SYSTEM/bought/freecad_macros/
       Size:      42.3 x 42.3 x 40 mm body, 5mm shaft x 24mm
       Notes:     Add corner mounting holes M3x4, shaft on +Z face.
       Time:      ~15 min

  5. HTD 5M pulleys
       Location:  06_DRIVE_SYSTEM/bought/freecad_macros/
       HTD 5M 60T:  OD ~97.5mm, width 16mm, 12mm bore + clamp
                    (rides on drive shaft)
       HTD 5M 16T:  OD ~27.4mm, width 16mm, 5mm bore + clamp
                    (rides on motor shaft)
       Notes:     Tooth profile is HTD curve; for marketing we
                  can model as cylinder with cosmetic tooth cuts.
       Time:      ~20 min

  6. HTD 5M belt (closed loop)
       Location:  06_DRIVE_SYSTEM/bought/freecad_macros/
       Notes:     Generated as a closed Bezier sweep wrapping
                  around both pulleys.  Width 15mm, thickness 3mm.
                  Length depends on motor offset distance.
       Time:      ~15 min

  7. 6001-2RS bearings + 12mm shaft (FEYRINX h8)
       Location:  05_BEARINGS_SHAFT/bought/freecad_macros/
       Bearing:   28mm OD x 12mm ID x 8mm width, ×2
       Shaft:     12mm OD x (length per assembly) mm
       Notes:     Position bearings inside the BearingHousings_V2_5
                  pair.  Shaft passes through both, extends up to
                  drive hub, extends down to motor pulley.
       Time:      ~15 min

----------------------------------------------------------------
Batch 3: ELECTRONICS + DECOR (then final render + ChatGPT step)
----------------------------------------------------------------

  8. Yarn cones (proper conical bobbin, ×2)
       Location:  00_PROJECT_OVERVIEW/decor/freecad_macros/
       Size:      Base D70mm, top D40mm, height 130mm, hollow core
       Notes:     Two colors (red + blue) sitting on top of the
                  retainer ring area.  Pure decorative.
       Time:      ~10 min

  9. Electronics: Arduino Mega 2560, TB6600 driver, LRS-50 PSU
       Location:  02_ELECTRONICS/bought/freecad_macros/
       Sizes:     Mega    101 x 53 x 15  mm  (USB + jack on edges)
                  TB6600  96  x 56 x 33  mm  (heatsink fins)
                  LRS-50  99  x 82 x 30  mm  (terminal block side)
       Notes:     Mount underneath the wood mid-shelf, between
                  uprights, visible from front-low angle.
       Time:      ~30 min

  10. 7" touchscreen + 3D-printed mount arm
        Location: 02_ELECTRONICS/freecad_macros/  (screen)
                  02_ELECTRONICS/printed/freecad_macros/  (arm)
        Sizes:    Screen 165 x 100 x 10 mm
                  Arm:    parametric goose-neck or rigid arm,
                          mounts to 2020 upright on front-left
        Notes:    This completes the "marketing look."  Without
                  the tablet, the render reads as a workshop tool.
                  With it, it reads as a finished product.
        Time:     ~30 min

================================================================
EXTENSIONS TO MACHINE_DATUMS.md
================================================================

We'll add a new section to MACHINE_DATUMS.md for "Bought Parts
Dimensions" so every macro (current and future) references the
same constants:

    # Drive components (bought)
    NEMA17_BODY_W        = 42.3
    NEMA17_BODY_H        = 40.0
    NEMA17_SHAFT_D       = 5.0
    NEMA17_SHAFT_L       = 24.0
    NEMA17_MOUNT_PCD     = 31.0   # 4× M3
    PULLEY_60T_OD        = 97.5
    PULLEY_60T_BORE      = 12.0
    PULLEY_60T_W         = 16.0
    PULLEY_16T_OD        = 27.4
    PULLEY_16T_BORE      = 5.0
    PULLEY_16T_W         = 16.0
    BELT_HTD_W           = 15.0
    BELT_HTD_T           = 3.0
    BEARING_6001_OD      = 28.0
    BEARING_6001_ID      = 12.0
    BEARING_6001_W       = 8.0
    SHAFT_D              = 12.0   # h8 tolerance

    # Electronics (bought)
    MEGA_W, MEGA_D, MEGA_H = 101, 53, 15
    TB6600_W, TB6600_D, TB6600_H = 96, 56, 33
    LRS50_W, LRS50_D, LRS50_H = 99, 82, 30
    TOUCH_W, TOUCH_D, TOUCH_H = 165, 100, 10

================================================================
NEXT STEP
================================================================

Waiting for user to confirm approval cadence (B = three checkpoints).
Once confirmed, build Batch 1 (frame) -> commit -> Blender re-render ->
review -> Batch 2 -> commit -> re-render -> review -> Batch 3 ->
final render -> install Proxima -> feed render + brief to ChatGPT ->
deliver marketing illustration.

================================================================
END OF LOG
================================================================

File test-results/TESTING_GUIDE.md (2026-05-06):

# Sinker Ring Test Results

## Test Slice Validation (V1.2.1)

### Print Quality

**Visual Inspection:**
- [ ] Angled tips visible and well-defined
- [ ] No knife-edge geometry (should feel like subtle ramp)
- [ ] Sinker height variation visible (tapered near feeder)
- [ ] Smooth layer transitions

**Dimensions:**
- [ ] Sinker width: 1.3mm ±0.1mm
- [ ] Radial extension: 4.0mm ±0.1mm
- [ ] Tapered sinker height: ~3.4mm (near feeder)
- [ ] Full sinker height: ~4.0mm (away from feeder)

### Fit Test on Cylinder

**ID 115.3 (default clearance, 0.50mm/side):**
- [ ] Slides on smoothly
- [ ] Rotates freely by hand
- [ ] Minimal wobble when rotated
- [ ] No binding or resistance

**ID 115.1 (tighter clearance, 0.40mm/side):**
- [ ] Slides on smoothly or tight?
- [ ] Rotates freely or with resistance?
- [ ] Wobble vs 115.3?

**Decision:** Use ID _________ for full ring

### Yarn Test

**Setup:** Scrap yarn draped across one sinker

**Forward pull (against rotation):**
- [ ] Yarn catches on sinker
- [ ] Holds tension
- [ ] Doesn't slip off

**Backward pull (with rotation):**
- [ ] Yarn releases smoothly
- [ ] No snagging
- [ ] Clean release

### Go/No-Go Decision

**Print full ring if all checked:**
- [ ] Visual inspection passed
- [ ] Fit test passed (one ID chosen)
- [ ] Yarn test passed (catch & release works)

**Iterate V1.3 if any failed:**
- Issue: ___________________________
- Proposed fix: ___________________________

---

**Test Date:** _______________  
**Tester:** _______________  
**Notes:** _______________

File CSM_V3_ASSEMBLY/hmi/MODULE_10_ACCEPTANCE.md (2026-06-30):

# Module 10 HMI -- RC1 Acceptance Checklist

CAD freeze: 2026-06-29.  Physical validation pending.

This document is the gate between **CAD complete** (where Module 10 sits
today) and **manufacturing complete** (which the first full machine
assembly will determine).  Each box becomes a single doc-only commit
when verified.  When every box is ticked, Module 10 is permanently
frozen and the four current DRAFT parts (P07, P08, P09, P10) can be
promoted to RC1 in a single batch.

---

## Mechanical

- [ ] All STL files print without supports
- [ ] All holes fit their nominal hardware (M5, M2.5, M3) with at most light deburring
- [ ] M5 heat-set inserts seat fully in their pockets (B0DPQJ4W3Z)
- [ ] No interference between any two HMI parts when assembled
- [ ] All fasteners remain accessible after the assembly is complete
- [ ] Two mast base sockets seat fully over the 2020 mast extrusions
- [ ] Cross beam drops cleanly onto mast tops; 12 mm pocket engages
- [ ] Touchscreen frame's 4 corner windows accommodate the ELECROW PCD
- [ ] Tilt lock arc slot achieves full +/-20 deg tilt without binding
- [ ] Pi carrier hangs square below the beam
- [ ] Pi fan cover stacks on Pi carrier with 11 mm standoffs as planned

## Electrical

- [ ] Pi fan airflow verified to point toward Pi PCB (arrow on fan body)
- [ ] HDMI cable bend radius acceptable from Pi to touchscreen
- [ ] USB-C power cable bend radius acceptable
- [ ] LED strip wiring complete and routes through cable channel
- [ ] All cables fit into the rear cable channel (8 x 4 mm)
- [ ] Fan power wired correctly: red -> Pi pin 4 (+5V), black -> pin 6 (GND)
- [ ] Touchscreen powers up and displays at 1024 x 600
- [ ] Touchscreen touch input is responsive

## Assembly

- [ ] Assembly order validated against the macro print-block notes
- [ ] No hidden fasteners that require disassembling adjacent parts to access
- [ ] No tool-access impossibilities (screwdrivers, allen keys, heat-set tool)
- [ ] Assembly manual matches the hardware actually used (BOM)
- [ ] Stack-up budget verified (Pi Carrier 10 mm + Pi PCB 1.6 mm + Fan Cover
      standoff 11 mm clears the 10 mm fan body)
- [ ] Mast Base Socket V1.3 lateral T-nut bolts (M5 x 12) thread into 2020 slot
- [ ] Cross Beam V1.2 mast bolts (M5 x 30) self-tap into 2020 center bore
- [ ] No screwdriver clearance problems for the tilt lock thumb screws

## Documentation

- [ ] STEP exported for each part
- [ ] STL exported for each part
- [ ] PNG views generated for each part
- [ ] PDF drawing generated for each part
- [ ] Each macro reports volume, mass (PETG @ 1.27 g/cm^3), and CoM
- [ ] Each macro's wall-thickness check passes all rules
- [ ] machine_datums.py HMI_* block has no remaining hardcoded magic numbers
- [ ] Assembly notes in each macro's print block are current

## Promotion plan

When every box above is checked, in a single doc-only commit:

| Part | Current | After validation |
|---|---|---|
| P03 Pi Carrier | RC1 | RELEASE |
| P05 Touchscreen Frame | RC1 | RELEASE |
| P06 Display Tilt Lock | RC1 | RELEASE |
| P07 Rear Cable Cover | DRAFT | RC1 |
| P08 Cable Clamp | DRAFT | RC1 |
| P09 LED Strip Holder | DRAFT | RC1 |
| P10 Expansion Plate | DRAFT | RC1 |

P01, P02, P04 stay at their current status (FROZEN, FROZEN, RELEASE).

---

## Reference

Per-part files live under `CSM_V3_ASSEMBLY/hmi/<part>/`.  Each folder
contains the FreeCAD macro, the rendered STL + STEP, and the engineering
drawing (PNG + PDF).

Interface contract: `3D-Project/00_PROJECT_OVERVIEW/machine_datums.py`,
`HMI_*` block, marked `HMI_INTERFACE_VERSION = "1.0"`.

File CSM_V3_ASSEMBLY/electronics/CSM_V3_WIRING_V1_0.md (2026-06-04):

# CSM V3 — Electrical Wiring Diagram V1.0

**Status:** Day 1 deliverable, electronics bench-test prep
**Created:** 2026-05-28
**Scope:** Complete mains→DC→logic→actuator wiring + signal architecture
**Phase:** 1 (initial powered bring-up, hanging-weight take-down)

> This document defines the wiring before the bench test. Use it as the
> assembly traveler when wiring on plywood/cardboard. Mark off items as
> built. Any deviation gets noted in a revision so the final installed
> machine matches what's documented here.

---

## §0 Component inventory (from BOM V12)

| Item | P/N | Role | Voltage / current |
|---|---|---|---|
| **Mean Well S-250-24** | B07Y7L664K | Main PSU | 24 VDC, 10 A out (240 W) |
| **LM2596 buck #1** | (BOM V12) | 24 V → 5 V for Mega + servos | 5 V, ≤ 3 A |
| **LM2596 buck #2** | (BOM V12) | 24 V → 5 V for Pi 4 (isolated rail) | 5 V, ≤ 3 A |
| **Arduino Mega 2560 REV3** | B0046AMGW0 | Real-time controller | 5 V via VIN, ~50 mA |
| **Raspberry Pi 4 4 GB** | B07V5JTMV9 | UI / pattern logic | 5 V, ~1.5 A typical |
| **TB6600 stepper driver** | B08SG7L54W | NEMA 23 driver | 24 V power, 5 V logic |
| **NEMA 23 + 5:1 HG5 gearbox** | StepperOnline | Cylinder drive | 24 V, 2.8 A peak |
| **MG90S metal-gear servo × 8** | (BOM V12, 6 active + 2 spare) | Feeder actuators | 5 V, ~150 mA active each |
| **7" touchscreen + Pi case** | B07V5JTMV9 (incl.) | UI display | 5 V via Pi |
| **E-stop mushroom button** | (TBD if not in BOM) | Mains interlock | NC contact, 250 V/10 A rated min |
| **Servo extensions × 6** | B0FXMDCP1H | JST-XH 3-pin M-F | – |
| **Inline AC fuse + holder** | (panel-mount, BOM check) | Mains protection | 2 A slow-blow (T2AL250V) |

---

## §1 Overview block diagram

```
                    230 VAC mains (or 115 VAC, switch on PSU)
                              │
                              │  L (brown)        N (blue)        PE (green/yellow)
                              ▼
                       ┌─────────────┐
                       │  E-STOP     │  Mushroom NC, breaks L line
                       │  (latching) │  (option: break L AND N for double-pole safety)
                       └──────┬──────┘
                              │
                       ┌──────▼──────┐
                       │  2 A T fuse │  inline before PSU
                       └──────┬──────┘
                              │
            ┌─────────────────▼─────────────────┐
            │       Mean Well S-250-24          │
            │   AC in: L / N / FG (earth)       │
            │   DC out: +V (×2) / −V (×2)       │
            │   24 VDC @ 10 A max               │
            └────────┬────────┬─────────┬───────┘
                     │+V      │+V       │−V
                     │ (24 V bus)       │ (24 V GND bus)
        ┌────────────┼────────┼─────────┼──────────┐
        │            │        │         │          │
   ┌────▼───┐  ┌────▼───┐ ┌──▼────┐ ┌──▼─────┐  ┌─▼──────┐
   │ TB6600 │  │ Buck#1 │ │Buck#2 │ │ Fan    │  │ Future │
   │ 24V    │  │ 24→5V  │ │ 24→5V │ │(optional)│ │accessory│
   │ Power  │  │ 3A     │ │ 3A    │ │        │  │(spare) │
   └────┬───┘  └────┬───┘ └──┬────┘ └────────┘  └────────┘
        │           │5V      │5V
        │       ┌───▼────┐ ┌─▼─────────────┐
        │       │ Mega   │ │ Raspberry Pi 4 │
        │       │ VIN/5V │ │ via 5V GPIO    │
        │       │ + GND  │ │ (or USB-C)     │
        │       └───┬────┘ └───┬────────────┘
        │           │           │
        │      ┌────┴───┐       │   HDMI
        │      │ 6× MG90S│       └──► 7" Touchscreen
        │      │ servos │           (5V via Pi USB or buck)
        │      │ JST-XH │
        │      └────────┘
        │
   STEP/DIR/EN
        │
   ┌────▼──────────┐
   │ NEMA 23 + HG5 │
   │  gearbox      │
   │ (cylinder)    │
   └───────────────┘

   Mega ←UART/USB→ Pi 4    (telemetry + commands; 115200 baud default)

   PE (earth) bonded at PSU FG terminal → frame (if metal) → mains earth.
```

---

## §2 Power distribution detail

### §2.1 Mains side (DANGEROUS — do this last)

```
WALL OUTLET (NEMA 5-15 or your region)
   │
   │   L  ──[brown 16AWG, stranded, 600V-rated]──┐
   │   N  ──[blue 16AWG]──────────────────────┐  │
   │   PE ──[green/yellow 16AWG]──────┐        │  │
   │                                  │        │  │
   ▼                                  ▼        ▼  ▼
                                     PSU FG  E-STOP terminals
                                     terminal  │
                                               ▼
                                        2A T-fuse
                                               │
                                               ▼
                                        S-250-24 L, N
```

**Mains specs:**
- L (Live / Line / Hot) — **brown**
- N (Neutral) — **blue**
- PE (Protective Earth) — **green with yellow stripe**
- Wire: **16 AWG stranded, 600 V insulation** (THHN, SJOOW, or H05VV-F equivalent)
- E-stop: NC contact, latching mushroom, **double-pole preferred** (breaks L AND N)
- Inline fuse: **2 A slow-blow** (T2AL250V) panel-mounted between E-stop and PSU L terminal
- All mains connections via **ferrules** into screw terminals — no bare wire ends
- Heatshrink over every termination
- PSU input voltage selector switch: **set to 115 V or 230 V to match your mains BEFORE first power-on**

> ⚠ The PSU input switch is on the unit itself. Verify it matches your mains
> voltage with a multimeter on the wall outlet before plugging in. Wrong
> setting = instant smoke.

### §2.2 24 V DC bus

PSU output terminals (typically labeled `+V`, `+V`, `−V`, `−V` on the S-250) feed a small distribution arrangement. Easiest: a 4-position WAGO 221 or DIN-rail terminal block.

```
PSU +V ──────┬─────┬─────┬─────► TB6600 VCC
             │     │     └────► Buck #1 IN+ (Mega/servo 5V supply)
             │     └─────────► Buck #2 IN+ (Pi 5V supply)
             └───────────────► (spare for Phase 2)

PSU −V ──────┬─────┬─────┬─────► TB6600 GND
             │     │     └────► Buck #1 IN−
             │     └─────────► Buck #2 IN−
             └───────────────► (spare for Phase 2)
```

**24 V bus specs:**
- Trunk from PSU to distribution: **14 AWG** (2 m max to keep voltage drop <2 %)
- Branches: **16 AWG** to TB6600, **18 AWG** to bucks
- Optional but recommended: **10 A fast fuse on the +V trunk** between PSU and distribution (e.g. ATO blade fuse holder)
- Color: **red = +24 V**, **black = 0 V (GND)** — pick a convention and stick to it
- Ferrules on every conductor entering a screw terminal

### §2.3 5 V logic rails — TWO separate bucks

Two separate LM2596 modules. This decouples the Pi from servo/stepper transients.

```
Buck #1 OUT (5 V, ≤ 3 A) ──┬──► Mega VIN (5 V tolerant) + GND
                           │
                           └──► 6× MG90S servo V+ and GND
                               (signal wires go to Mega PWM pins)

Buck #2 OUT (5 V, ≤ 3 A) ──► Pi 4 5V pin (GPIO pin 2 or 4) + GND (pin 6)
                            (or via USB-C, see §2.4)
```

**5 V bus specs:**
- Adjust each LM2596 to **5.10 V ± 0.05 V** under no load **before** connecting downstream (use multimeter on a load-free buck output)
- 100 µF electrolytic across each buck output (input + output) for transient suppression — many LM2596 modules already have this
- **Servo power and Pi power must NOT share the same buck.** Servo current spikes cause voltage dips that crash the Pi.
- **Mega and servos can share Buck #1** — Mega is tolerant of small dips and the analog reference doesn't depend on VIN

### §2.4 Pi 4 power option

Pi 4 needs a clean 5 V at up to 3 A. Two options:

**Option A (recommended for bench test):** Pi from its own wall-wart USB-C supply (the BOM CanaKit starter includes one). Keeps Pi totally isolated from machine power during bench testing. The machine still works if Pi is unplugged.

**Option B (integrated):** Buck #2 output → Pi 4 GPIO pin 2 (5 V) and pin 6 (GND). Skip the USB-C connector. This is cleaner for the final installation but harder to debug.

For Day-1 bench test → **Option A**. Switch to Option B once the bench test confirms everything works.

---

## §3 Signal architecture

### §3.1 Mega ↔ Pi 4 link

```
Mega                                Pi 4
─────                              ─────
 USB-B port  ── USB cable ──►  USB 3.0 port (any)
                                  │
                                  └── shows up as /dev/ttyACM0 on Pi
                                      (or /dev/ttyUSB0 if FT232)

UART speed: 115200 baud, 8N1
Protocol:   line-based ASCII for bring-up;
            switch to packetized binary at Phase 2
```

Pi sends commands like `SET_SPEED 250\n`, Mega responds `OK\n` or `FAULT <code>\n`. Telemetry from Mega comes back as `T <encoder> <servo_pos> <state>\n` at ~10 Hz.

(Full protocol gets defined in Day-2 deliverable; this diagram shows the physical link only.)

### §3.2 Mega ↔ TB6600

```
Mega digital pins         TB6600 inputs
─────────────────         ─────────────
D5  ──── 220Ω ──────────► PUL+   (step pulse)
D6  ──── 220Ω ──────────► DIR+   (direction)
D7  ──── 220Ω ──────────► ENA+   (enable, active LOW)
GND  ──────────────────► PUL− / DIR− / ENA−  (common cathode)
```

**TB6600 microstep & current** settings via on-board DIP switches:
- Microstep: **8 µstep** for Phase 1 (smooth, plenty of resolution)
- Current: **2.5 A** (NEMA 23 rated 2.8 A; leave 10 % margin)
- Verify against the table printed on the TB6600 enclosure

### §3.3 Mega ↔ Servos

Six MG90S servos, three-pin JST-XH each (signal / V+ / GND).

```
Mega PWM pins              Each servo
─────────────              ──────────
D9  ─────────────────────► Servo 0 signal
D10 ─────────────────────► Servo 1 signal
D11 ─────────────────────► Servo 2 signal
D12 ─────────────────────► Servo 3 signal
D44 ─────────────────────► Servo 4 signal     (Timer 5)
D45 ─────────────────────► Servo 5 signal     (Timer 5)

Servo V+  ◄── Buck #1 5 V rail
Servo GND ◄── Buck #1 GND rail (also common with Mega GND)
```

**Important:** Mega GND and Buck #1 GND **must be tied together** at one point — otherwise the PWM signal has no common reference. Single short link between Mega GND pin and Buck #1 GND output. Star ground from the buck output, not chain.

(Servo channels 6 and 7 are spares; wire only if needed.)

### §3.4 NEMA 23 motor wiring

```
TB6600 motor outputs       NEMA 23 (4-wire, bipolar)
────────────────────       ────────────────────────
A+ ─────────────────────► A coil +  (typically red)
A− ─────────────────────► A coil −  (typically blue)
B+ ─────────────────────► B coil +  (typically green)
B− ─────────────────────► B coil −  (typically black)
```

Verify your specific motor's pinout against its datasheet — colors vary by manufacturer. If the motor spins the wrong direction during first test, swap A+ ↔ A− (or B+ ↔ B−).

### §3.5 E-stop signal path

The mushroom button has TWO contact sets:

```
Contact set 1: BREAKS MAINS L line     (primary safety, in §2.1)
Contact set 2: GROUNDS Mega D2 pin     (signal to firmware)
```

When pressed:
- **Hardware-level:** mains is physically broken, PSU shuts off, motors lose power immediately
- **Signal-level:** D2 reads HIGH on press (via 10 kΩ pull-up) — Mega ISR sets state machine to `FAULT_ESTOP`, halts any commanded motion, signals Pi to display the fault

Pi can NOT release the E-stop. The user must twist-release the mushroom button manually. After release, Mega boots clean to `IDLE` state and Pi prompts the user to confirm before re-enabling.

---

## §4 Earthing strategy

Single-point earth at the PSU. **Do NOT create earth loops.**

```
Mains PE (wall outlet, green/yellow)
   │
   ▼
PSU FG terminal  ◄── single bonding point
   │
   ├──► Frame earth (only if metal frame; wood frame = skip)
   │
   ├──► Mega GND (via Buck #1 GND chain, not separate wire)
   │
   └──► Pi 4 GND (via Buck #2 GND, or via USB cable to Mega)
```

DC side `−V` of the PSU is usually internally bonded to FG inside the PSU. Don't add a second bond elsewhere — that creates a ground loop and produces noise on the 5 V rails.

---

## §5 Wire / connector / fuse table

| Run | Wire | Color | Connector | Fuse |
|---|---|---|---|---|
| Mains L (E-stop ⇄ fuse ⇄ PSU L) | 16 AWG stranded 600 V | brown | ferrule into screw terminal | 2 A T (slow-blow) |
| Mains N | 16 AWG 600 V | blue | ferrule | – |
| Mains PE | 16 AWG 600 V | green/yellow | ring-lug to PSU FG | – |
| 24 V trunk (PSU → distribution) | 14 AWG | red | ferrule | 10 A fast (optional) |
| 24 V → TB6600 | 16 AWG | red | ferrule | – |
| 0 V trunk + branches | matched gauge | black | ferrule | – |
| 24 V → buck #1, buck #2 | 18 AWG | red / black | ferrule | – |
| 5 V → Mega VIN | 22 AWG | red | dupont or screw to Mega VIN | – |
| 5 V → Pi (if internal) | 18 AWG | red / black | 2.5×5.5 mm barrel OR direct to GPIO | – |
| Servo V+ / GND | 22 AWG | red / brown | JST-XH 3-pin | – |
| Servo signal | 22 AWG | orange | JST-XH 3-pin | – |
| TB6600 step / dir / en | 24 AWG | varied | dupont | – |
| Mega ↔ Pi | USB-A to USB-B | factory cable | – | – |
| NEMA 23 motor (4-wire) | 18 AWG | per motor | ferrule into TB6600 screw terminals | – |
| E-stop signal to Mega D2 | 24 AWG | yellow | dupont | – |

---

## §6 Wire color convention (lock now)

| Color | Meaning | Used for |
|---|---|---|
| Brown | Mains Live | Mains side only |
| Blue | Mains Neutral | Mains side only |
| Green/yellow | Mains PE | Earth bonding only |
| **Red** | DC positive (24 V or 5 V depending on context, labeled with tape) | All DC supply rails |
| **Black** | DC return (0 V / GND) | All DC returns |
| Orange | PWM / step / signal | Mega outputs to actuators |
| Yellow | Sensor / input signal | Mega inputs (E-stop, encoder, limit) |
| White | UART / SPI / I²C | Inter-controller signals |
| Grey | Ground reference, signal common | Multi-board GND ties |

> Pick this convention and **never** use a brown wire for anything except mains Live. The day you have to chase a fault at 2 AM you will thank yourself.

---

## §7 Bench-test procedure (Day 1 evening)

Build the wiring on a sheet of plywood / cardboard. Do not energize the machine frame yet.

### Stage 1 — PSU only

1. ☐ Wire mains side per §2.1 with E-stop and fuse
2. ☐ Verify PSU input voltage selector matches your mains (slide switch)
3. ☐ With NOTHING connected to PSU output: plug in
4. ☐ Multimeter on PSU output: should read **24.0 V ± 0.2 V**
5. ☐ Press E-stop: PSU should de-energize within ~1 second
6. ☐ Release E-stop: PSU re-energizes
7. ☐ Adjust the +V trimpot if needed (you measured its location for the guard)

### Stage 2 — Bucks + Mega

1. ☐ E-stop pressed (PSU off)
2. ☐ Wire Buck #1 input to 24 V bus
3. ☐ With Buck #1 output disconnected, release E-stop, adjust Buck #1 to **5.10 V** with multimeter, then E-stop again
4. ☐ Wire Buck #1 output to Mega VIN and GND
5. ☐ Release E-stop. Mega power LED should light. Plug USB to laptop.
6. ☐ Upload a blink sketch. LED 13 should blink.
7. ☐ Press E-stop. Mega should lose power within 1 second.

### Stage 3 — Bucks #2 + Pi

1. ☐ Repeat the same procedure for Buck #2 — adjust to 5.10 V no-load first
2. ☐ Wire Buck #2 to Pi 5 V GPIO (or use the USB-C wall wart for Option A)
3. ☐ Pi should boot, display should come up on the 7" touchscreen
4. ☐ E-stop test: Pi should also lose power if Buck #2 is fed from machine PSU (Option B); if using Option A wall wart, Pi stays up but Mega goes down — verify Pi gracefully shows "Mega disconnected"

### Stage 4 — TB6600 + NEMA 23

1. ☐ E-stop pressed. Wire TB6600 power (24 V), step/dir/enable (Mega D5/D6/D7), and motor coils.
2. ☐ Set TB6600 DIP switches: 8 µstep, 2.5 A current limit
3. ☐ Release E-stop. Upload a slow-pulse sketch to Mega.
4. ☐ Motor should rotate slowly and smoothly. If it stutters or skips: check microstep + current settings.
5. ☐ E-stop press: motor should stop immediately (mains gone)

### Stage 5 — Servos

1. ☐ E-stop pressed. Wire one MG90S to Mega D9 + Buck #1 5 V rail
2. ☐ Release E-stop. Run a sweep sketch (90° back and forth).
3. ☐ Confirm clean motion. If the servo jitters: voltage too low or noise on 5 V rail (separate Pi to a different buck).
4. ☐ Add servos one at a time up to 6. Verify all positions hold.

### Pass criteria

- ☐ PSU output stable 24.00 ± 0.10 V under combined load (stepper + 6 servos commanded)
- ☐ Both 5 V rails stable 5.00 ± 0.10 V under same load
- ☐ E-stop reliably kills power (both stages tested 3 times)
- ☐ Mega + Pi both boot clean after E-stop release
- ☐ Stepper motion is smooth (no skipping, no audible whine beyond normal stepper hum)
- ☐ All 6 servos hold position without jitter

If all pass: electronics are validated, no machine-installation issues will be electrical. If any fail: fix on the bench, not in the machine.

---

## §8 Open items / questions

These are TBD or need decisions before the final install (not blocking the bench test):

- [ ] Mains plug type for your region (US NEMA 5-15? Europe Schuko? UK BS 1363?) — affects the inlet connector spec
- [ ] E-stop mushroom button: BOM doesn't show this purchased yet — confirm it's on order or order one. Look for **22 mm panel-mount, NC + NC (double pole), latching, rated 10 A / 250 V min**
- [ ] AC inlet: panel-mount IEC-C14 (kettle plug) is standard for machines like this and lets you use any region's cable — recommend this over hard-wired mains
- [ ] PSU mounting: confirm orientation on deck (vents should not be obstructed)
- [ ] Future encoder on cylinder: where will encoder signals route? Add 2 wires (A, B + V+ + GND = 4 wires) to the 24V-bus side now if possible
- [ ] Cable strain reliefs: 1 grommet per cable entry point on the deck

---

## §9 Revision log

| Rev | Date | Author | Change |
|---|---|---|---|
| V1.0 | 2026-05-28 | claude | Initial wiring diagram, derived from BOM V12 + datasheet S-250-24 |

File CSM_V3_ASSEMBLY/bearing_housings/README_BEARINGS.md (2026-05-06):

# Bearing Housing Blocks — Delivery Package

## Contents
- `freecad_macros/CSM_V3_BearingHousings_V1.FCMacro` — FreeCAD macro (both blocks)
- `blueprints/CSM_V3_BearingHousings_V1_VisualDiagram.svg` — Visual blueprint

## Usage
1. Open FreeCAD
2. Macro → Macros... → Add existing → point to the FCMacro file
3. Run the macro
4. STL, PNG, SVG, and chart will auto-export to:
   - `C:\3D-Project\01_MECHANICAL\05_BEARINGS_SHAFT\` (STL root)
   - `C:\3D-Project\01_MECHANICAL\05_BEARINGS_SHAFT\images\` (PNGs)
   - `C:\3D-Project\01_MECHANICAL\05_BEARINGS_SHAFT\blueprints\` (SVG)

## Parts produced
- TOP block: 60×60×20mm, 1× 6001-2RS
- BOTTOM block: 70×70×30mm, 2× 6001-2RS + 1× 51101 thrust

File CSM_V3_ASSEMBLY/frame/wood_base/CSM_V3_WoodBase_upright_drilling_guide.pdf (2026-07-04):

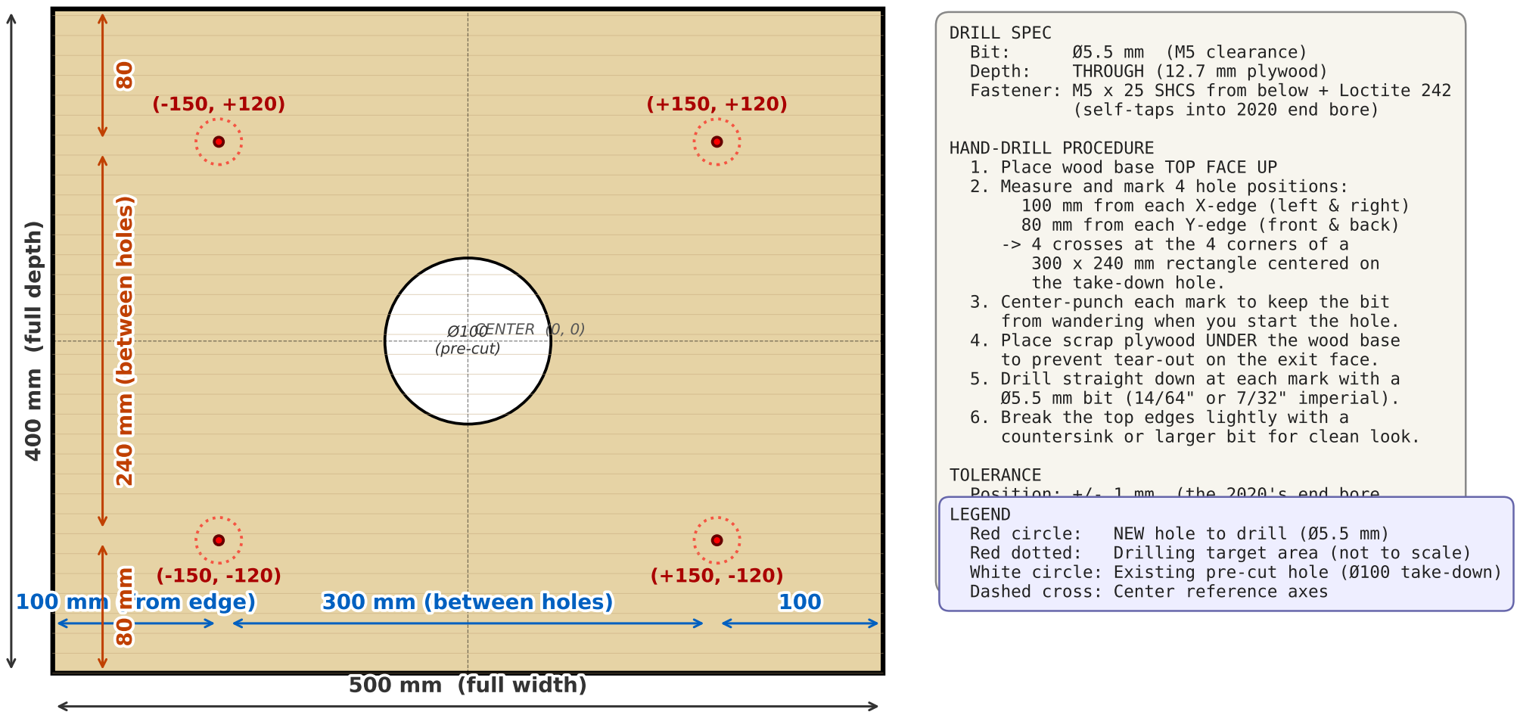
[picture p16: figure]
Ø100CENTER (0, 0) (pre-cut); DRILL SPEC; Bit:; (M5 clearance); Depth:; THROUGH (12.7 mm plywood); (self-taps into 2020 end bore); HAND-DRILL PROCEDURE 1. Place wood base TOP FACE UP 2. Measure and mark 4 hole positions: 100 mm from each X-edge (left & right) 80 mm from each Y-edge (front & back) -> 4 crosses at the 4 corners of a 300 x 240 mm rectangle centered on the take-down hole.; from wandering when you start the hole.; to prevent tear-out on the exit face.; Ø5.5 mm bit (14/64" or 7/32" imperial). 6. Break the top edges lightly with a; TOLERANCE; Position: +/- 1 mm; (the 2020's end bore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

Fastener: M5 x 25 SHCS from below + Loctite 242

3. Center-punch each mark to keep the bit
4. Place scrap plywood UNDER the wood base
5. Drill straight down at each mark with a

countersink or larger bit for clean look.

Squareness: keep the bit vertical -- a slanted
Red dotted: Drilling target area (not to scale) White circle: Existing pre-cut hole (Ø100 take-down)

## CSM V3 -- WOOD BASE | Upright hole drilling template 500 x 400 x 12.7 mm Baltic Birch plywood, top face shown 4 x M5 clearance holes at (±150, ±120) mm from center -- drill through, both sides

github.com/leoalex196912/ChatGistory * CSM_V3_ASSEMBLY/frame/wood_base/ * 2026-06-29

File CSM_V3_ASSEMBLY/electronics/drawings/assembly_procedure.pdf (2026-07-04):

CSM V3 | ASSEMBLY PROCEDURE
Wood Base V1.1 Electrical Mounting | Rev V1.0 | ~4-6 h | Page 1: Drilling + Mechanical
BUILDER: | DATE:
PHASE A | PREPARATION (30 min)
1. Print drilling_guide.pdf at 1:1 scale. Verify with ruler that 50 mm marks measure 50 mm.
2. Gather all hardware per hardware_order_sheet.pdf checklist.
3. Stage tools: drill, drill bits (Ø2 / Ø3.2 / Ø3.5 / Ø4.5 / Ø5.5 / Ø100 saw), screwdrivers, wrenches, calipers.
4. Wood-base orientation: long edge = X (500 mm), short edge = Y (400 mm). Mark "FRONT" arrow on -Y edge.
5. Mark center of wood base (datum 0, 0). Draw faint +X and +Y axis lines with pencil.
6. Tape the drilling_guide printout to the wood with axis lines aligned to the printed datum.

## PHASE B DRILLING (1 h)

1. Center-punch ALL 21 hole positions through the paper template into the wood.
2. Remove paper template. Pilot-drill every position with Ø 2.0 mm bit.
3. Drill 10 × Ø 3.2 mm holes (Mega ×4, Buck#1 ×2, Buck#2 ×2, Terminal ×2).
4. Drill 2 × Ø 3.5 mm holes (TB6600 flange).
5. Drill 4 × Ø 4.5 mm holes (PSU chassis).
6. Drill 4 × Ø 5.5 mm holes (NEMA 23 motor flange).
7. Cut Ø 100 mm take-down opening with hole saw or jigsaw, centered on datum.
8. (Optional) Counterbore PSU + Motor holes Ø 8 × 2 mm from UNDERSIDE to recess nuts.
9. Vacuum dust. Verify hole positions with calipers | tolerance ±1 mm.
PHASE C | MECHANICAL MOUNTING (1.5 h)
1. Dry-fit PSU at (-195, 0). Verify all 4 chassis screws align with Ø 4.5 holes.
2. Bolt PSU: M4 × 30 + washer top, washer + nut bottom. Tighten cross-pattern.
3. Set NEMA 23 + HG5 motor at (+85, -47), shaft pointing UP. Verify gearbox orientation.
4. Bolt motor: M5 × 35 + washer + lock washer + nut. Apply Loctite 243 on threads.
5. Mount TB6600 at (+200, -47). Bolt: M3 × 25 + washer + nut. Terminals face +X (edge).
6. Install M3 × 10 mm nylon standoffs at the 4 Mega positions (+200, +75 area).
7. Mount Arduino Mega on standoffs. Bolt: M3 × 30 + washer + nut. USB port faces +X.
8. Mount LM2596 Buck #1 at (-50, +160) using M3 × 22 + 5 mm standoff (or 3M VHB).
9. Mount LM2596 Buck #2 at (+50, +160) same method as Buck #1.
10. Mount 24V terminal block at (0, +180). Use M3 × 22 OR DIN-rail clip.
11. Build operator panel per operator_panel.pdf. L-bracket to FRONT (-Y) edge of wood base.
github.com/leoalex196912/ChatGistory | CSM V3 | Assembly Procedure | Page 1 of 2

CSM V3 | ASSEMBLY PROCEDURE
Wood Base V1.1 Electrical Mounting | Rev V1.0 | ~4-6 h | Page 2: Wiring + Verify
BUILDER: | DATE:
PHASE D | WIRING (2-3 h, see CSM_V3_WIRING_V1_0.md)
1. Wire mains FIRST with PSU DISCONNECTED from wall. 16 AWG brown/blue/g-y.
2. Order: wall | E-stop | 2 A T-fuse | PSU L/N/PE terminals.
3. Wire 24 V DC bus: PSU +V/-V | 24V terminal block. 14 AWG with ferrules.
4. Branch 24 V to TB6600 power, Buck #1 IN, Buck #2 IN.
5. BEFORE downstream loads: power bucks alone, adjust each to 5.10 V no-load.
6. Wire 5 V #1 | Mega VIN + GND + 6× servo headers. Single-point GND.
7. Wire 5 V #2 | Pi GPIO 5 V + GND (or USB-C wall wart for bench).
8. Wire Mega | TB6600 step/dir/en (D5/D6/D7 with 220 | each).
9. Wire NEMA 23 4-wire to TB6600 A+/A-/B+/B- (check motor color code).
10. Wire E-stop second NC contact Mega D2 with 10 k pull-up.
11. Cable-tie all wiring per ELECTRICAL_LAYOUT §2.6 (mains FRONT, 24V BACK).
12. Label every wire bundle with tape: AC / 24V / 5V / SIG.

## DO NOT CONNECT MAINS UNTIL BENCH-TEST PHASE 1 PASSES

## PHASE E VERIFY BEFORE FIRST POWER (15 min)

1. Re-check every bolt is tight; no loose washers visible.
2. Confirm all 4 motor bolts have lock washers + Loctite 243.
3. Multimeter continuity: PE wire wall plug PSU FG. Must be < 1 .
4. Multimeter resistance: PSU +V to -V terminals UNPOWERED. Should be high (>1 k ).
5. No bare conductor exposed at any mains terminal. Cap unused terminals.
6. Verify wire colors: brown=L, blue=N, green/yellow=PE, red=+, black=GND.
7. PSU voltage selector SWITCH set to match your mains (115 OR 230 V).
8. Photograph the finished assembly (top + 4 sides) for the record.
9. Proceed to BENCH-TEST CHECKLIST (bench_test_checklist.pdf).

### NOTES / DEVIATIONS:

github.com/leoalex196912/ChatGistory | CSM V3 | Assembly Procedure | Page 2 of 2

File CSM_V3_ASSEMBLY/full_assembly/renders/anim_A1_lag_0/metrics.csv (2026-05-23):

frame | theta_cyl_deg | needle_x_mm | needle_y_mm | needle_z_mm | yarn_owner_deg | yarn_state | yarn_x_mm | yarn_y_mm | yarn_z_mm | angular_dist_to_owner_deg | capture_margin_mm | capture_offset_xy_mm | capture_3d_distance_mm | in_capture_window
0 | 0.00 | 56.150 | 0.000 | 264.000 | 0.0 | captured | 56.150 | 0.000 | 264.000 | 0.00 | +0.000 | 0.000 | 0.000 | 1
1 | 5.00 | 55.936 | 4.894 | 263.464 | 0.0 | captured | 56.150 | 0.000 | 264.000 | 5.00 | +0.536 | 4.898 | 4.928 | 1
2 | 10.00 | 55.297 | 9.750 | 262.000 | 0.0 | captured | 56.150 | 0.000 | 264.000 | 10.00 | +2.000 | 9.788 | 9.990 | 1
3 | 15.00 | 54.237 | 14.533 | 260.000 | 0.0 | captured | 56.150 | 0.000 | 264.000 | 15.00 | +4.000 | 14.658 | 15.194 | 1
4 | 20.00 | 52.764 | 19.204 | 258.000 | 0.0 | captured | 56.150 | 0.000 | 264.000 | 20.00 | +6.000 | 19.501 | 20.403 | 1
5 | 25.00 | 50.889 | 23.730 | 256.536 | 0.0 | captured | 56.150 | 0.000 | 264.000 | 25.00 | +7.464 | 24.306 | 25.426 | 1
6 | 30.00 | 48.627 | 28.075 | 256.000 | 0.0 | captured | 56.150 | 0.000 | 264.000 | 30.00 | +8.000 | 29.065 | 30.146 | 1
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

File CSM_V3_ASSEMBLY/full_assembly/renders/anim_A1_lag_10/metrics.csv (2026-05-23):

frame | theta_cyl_deg | needle_x_mm | needle_y_mm | needle_z_mm | yarn_owner_deg | yarn_state | yarn_x_mm | yarn_y_mm | yarn_z_mm | angular_dist_to_owner_deg | capture_margin_mm | capture_offset_xy_mm | capture_3d_distance_mm | in_capture_window
0 | 0.00 | 56.150 | 0.000 | 264.000 | 10.0 | captured | 55.297 | 9.750 | 262.000 | 10.00 | -2.000 | 9.788 | 9.990 | 1
1 | 5.00 | 55.936 | 4.894 | 263.464 | 10.0 | captured | 55.297 | 9.750 | 262.000 | 5.00 | -1.464 | 4.898 | 5.113 | 1
2 | 10.00 | 55.297 | 9.750 | 262.000 | 10.0 | captured | 55.297 | 9.750 | 262.000 | 0.00 | +0.000 | 0.000 | 0.000 | 1
3 | 15.00 | 54.237 | 14.533 | 260.000 | 10.0 | captured | 55.297 | 9.750 | 262.000 | 5.00 | +2.000 | 4.898 | 5.291 | 1
4 | 20.00 | 52.764 | 19.204 | 258.000 | 10.0 | captured | 55.297 | 9.750 | 262.000 | 10.00 | +4.000 | 9.788 | 10.573 | 1
5 | 25.00 | 50.889 | 23.730 | 256.536 | 10.0 | captured | 55.297 | 9.750 | 262.000 | 15.00 | +5.464 | 14.658 | 15.643 | 1
6 | 30.00 | 48.627 | 28.075 | 256.000 | 10.0 | captured | 55.297 | 9.750 | 262.000 | 20.00 | +6.000 | 19.501 | 20.403 | 1
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

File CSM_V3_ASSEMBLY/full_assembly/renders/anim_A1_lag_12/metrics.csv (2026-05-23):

frame | theta_cyl_deg | needle_x_mm | needle_y_mm | needle_z_mm | yarn_owner_deg | yarn_state | yarn_x_mm | yarn_y_mm | yarn_z_mm | angular_dist_to_owner_deg | capture_margin_mm | capture_offset_xy_mm | capture_3d_distance_mm | in_capture_window
0 | 0.00 | 56.150 | 0.000 | 264.000 | 12.0 | captured | 54.923 | 11.674 | 261.236 | 12.00 | -2.764 | 11.739 | 12.060 | 1
1 | 5.00 | 55.936 | 4.894 | 263.464 | 12.0 | captured | 54.923 | 11.674 | 261.236 | 7.00 | -2.228 | 6.856 | 7.209 | 1
2 | 10.00 | 55.297 | 9.750 | 262.000 | 12.0 | captured | 54.923 | 11.674 | 261.236 | 2.00 | -0.764 | 1.960 | 2.104 | 1
3 | 15.00 | 54.237 | 14.533 | 260.000 | 12.0 | captured | 54.923 | 11.674 | 261.236 | 3.00 | +1.236 | 2.940 | 3.189 | 1
4 | 20.00 | 52.764 | 19.204 | 258.000 | 12.0 | captured | 54.923 | 11.674 | 261.236 | 8.00 | +3.236 | 7.834 | 8.476 | 1
5 | 25.00 | 50.889 | 23.730 | 256.536 | 12.0 | captured | 54.923 | 11.674 | 261.236 | 13.00 | +4.700 | 12.713 | 13.554 | 1
6 | 30.00 | 48.627 | 28.075 | 256.000 | 12.0 | captured | 54.923 | 11.674 | 261.236 | 18.00 | +5.236 | 17.568 | 18.331 | 1
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

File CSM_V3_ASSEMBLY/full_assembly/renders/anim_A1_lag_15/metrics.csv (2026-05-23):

frame | theta_cyl_deg | needle_x_mm | needle_y_mm | needle_z_mm | yarn_owner_deg | yarn_state | yarn_x_mm | yarn_y_mm | yarn_z_mm | angular_dist_to_owner_deg | capture_margin_mm | capture_offset_xy_mm | capture_3d_distance_mm | in_capture_window
0 | 0.00 | 56.150 | 0.000 | 264.000 | 15.0 | captured | 54.237 | 14.533 | 260.000 | 15.00 | -4.000 | 14.658 | 15.194 | 1
1 | 5.00 | 55.936 | 4.894 | 263.464 | 15.0 | captured | 54.237 | 14.533 | 260.000 | 10.00 | -3.464 | 9.788 | 10.383 | 1
2 | 10.00 | 55.297 | 9.750 | 262.000 | 15.0 | captured | 54.237 | 14.533 | 260.000 | 5.00 | -2.000 | 4.898 | 5.291 | 1
3 | 15.00 | 54.237 | 14.533 | 260.000 | 15.0 | captured | 54.237 | 14.533 | 260.000 | 0.00 | +0.000 | 0.000 | 0.000 | 1
4 | 20.00 | 52.764 | 19.204 | 258.000 | 15.0 | captured | 54.237 | 14.533 | 260.000 | 5.00 | +2.000 | 4.898 | 5.291 | 1
5 | 25.00 | 50.889 | 23.730 | 256.536 | 15.0 | captured | 54.237 | 14.533 | 260.000 | 10.00 | +3.464 | 9.788 | 10.383 | 1
6 | 30.00 | 48.627 | 28.075 | 256.000 | 15.0 | captured | 54.237 | 14.533 | 260.000 | 15.00 | +4.000 | 14.658 | 15.194 | 1
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

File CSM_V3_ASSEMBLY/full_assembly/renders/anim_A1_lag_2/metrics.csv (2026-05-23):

frame | theta_cyl_deg | needle_x_mm | needle_y_mm | needle_z_mm | yarn_owner_deg | yarn_state | yarn_x_mm | yarn_y_mm | yarn_z_mm | angular_dist_to_owner_deg | capture_margin_mm | capture_offset_xy_mm | capture_3d_distance_mm | in_capture_window
0 | 0.00 | 56.150 | 0.000 | 264.000 | 2.0 | captured | 56.116 | 1.960 | 263.913 | 2.00 | -0.087 | 1.960 | 1.962 | 1
1 | 5.00 | 55.936 | 4.894 | 263.464 | 2.0 | captured | 56.116 | 1.960 | 263.913 | 3.00 | +0.448 | 2.940 | 2.974 | 1
2 | 10.00 | 55.297 | 9.750 | 262.000 | 2.0 | captured | 56.116 | 1.960 | 263.913 | 8.00 | +1.913 | 7.834 | 8.064 | 1
3 | 15.00 | 54.237 | 14.533 | 260.000 | 2.0 | captured | 56.116 | 1.960 | 263.913 | 13.00 | +3.913 | 12.713 | 13.301 | 1
4 | 20.00 | 52.764 | 19.204 | 258.000 | 2.0 | captured | 56.116 | 1.960 | 263.913 | 18.00 | +5.913 | 17.568 | 18.536 | 1
5 | 25.00 | 50.889 | 23.730 | 256.536 | 2.0 | captured | 56.116 | 1.960 | 263.913 | 23.00 | +7.377 | 22.389 | 23.573 | 1
6 | 30.00 | 48.627 | 28.075 | 256.000 | 2.0 | captured | 56.116 | 1.960 | 263.913 | 28.00 | +7.913 | 27.168 | 28.297 | 1
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

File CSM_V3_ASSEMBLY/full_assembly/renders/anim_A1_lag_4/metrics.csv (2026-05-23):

frame | theta_cyl_deg | needle_x_mm | needle_y_mm | needle_z_mm | yarn_owner_deg | yarn_state | yarn_x_mm | yarn_y_mm | yarn_z_mm | angular_dist_to_owner_deg | capture_margin_mm | capture_offset_xy_mm | capture_3d_distance_mm | in_capture_window
0 | 0.00 | 56.150 | 0.000 | 264.000 | 4.0 | captured | 56.013 | 3.917 | 263.654 | 4.00 | -0.346 | 3.919 | 3.934 | 1
1 | 5.00 | 55.936 | 4.894 | 263.464 | 4.0 | captured | 56.013 | 3.917 | 263.654 | 1.00 | +0.190 | 0.980 | 0.998 | 1
2 | 10.00 | 55.297 | 9.750 | 262.000 | 4.0 | captured | 56.013 | 3.917 | 263.654 | 6.00 | +1.654 | 5.877 | 6.106 | 1
3 | 15.00 | 54.237 | 14.533 | 260.000 | 4.0 | captured | 56.013 | 3.917 | 263.654 | 11.00 | +3.654 | 10.763 | 11.367 | 1
4 | 20.00 | 52.764 | 19.204 | 258.000 | 4.0 | captured | 56.013 | 3.917 | 263.654 | 16.00 | +5.654 | 15.629 | 16.620 | 1
5 | 25.00 | 50.889 | 23.730 | 256.536 | 4.0 | captured | 56.013 | 3.917 | 263.654 | 21.00 | +7.118 | 20.465 | 21.668 | 1
6 | 30.00 | 48.627 | 28.075 | 256.000 | 4.0 | captured | 56.013 | 3.917 | 263.654 | 26.00 | +7.654 | 25.262 | 26.396 | 1
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

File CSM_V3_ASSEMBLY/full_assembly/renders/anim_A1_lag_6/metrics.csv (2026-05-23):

frame | theta_cyl_deg | needle_x_mm | needle_y_mm | needle_z_mm | yarn_owner_deg | yarn_state | yarn_x_mm | yarn_y_mm | yarn_z_mm | angular_dist_to_owner_deg | capture_margin_mm | capture_offset_xy_mm | capture_3d_distance_mm | in_capture_window
0 | 0.00 | 56.150 | 0.000 | 264.000 | 6.0 | captured | 55.842 | 5.869 | 263.236 | 6.00 | -0.764 | 5.877 | 5.927 | 1
1 | 5.00 | 55.936 | 4.894 | 263.464 | 6.0 | captured | 55.842 | 5.869 | 263.236 | 1.00 | -0.228 | 0.980 | 1.006 | 1
2 | 10.00 | 55.297 | 9.750 | 262.000 | 6.0 | captured | 55.842 | 5.869 | 263.236 | 4.00 | +1.236 | 3.919 | 4.110 | 1
3 | 15.00 | 54.237 | 14.533 | 260.000 | 6.0 | captured | 55.842 | 5.869 | 263.236 | 9.00 | +3.236 | 8.811 | 9.386 | 1
4 | 20.00 | 52.764 | 19.204 | 258.000 | 6.0 | captured | 55.842 | 5.869 | 263.236 | 14.00 | +5.236 | 13.686 | 14.653 | 1
5 | 25.00 | 50.889 | 23.730 | 256.536 | 6.0 | captured | 55.842 | 5.869 | 263.236 | 19.00 | +6.700 | 18.535 | 19.709 | 1
6 | 30.00 | 48.627 | 28.075 | 256.000 | 6.0 | captured | 55.842 | 5.869 | 263.236 | 24.00 | +7.236 | 23.348 | 24.444 | 1
7 | 35.00 | 45.995 | 32.206 | 256.000 | 6.0 | captured | 55.842 | 5.869 | 263.236 | 29.00 | +7.236 | 28.118 | 29.034 | 1
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

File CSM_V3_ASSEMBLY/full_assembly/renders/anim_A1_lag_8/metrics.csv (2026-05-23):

frame | theta_cyl_deg | needle_x_mm | needle_y_mm | needle_z_mm | yarn_owner_deg | yarn_state | yarn_x_mm | yarn_y_mm | yarn_z_mm | angular_dist_to_owner_deg | capture_margin_mm | capture_offset_xy_mm | capture_3d_distance_mm | in_capture_window
0 | 0.00 | 56.150 | 0.000 | 264.000 | 8.0 | captured | 55.604 | 7.815 | 262.677 | 8.00 | -1.323 | 7.834 | 7.945 | 1
1 | 5.00 | 55.936 | 4.894 | 263.464 | 8.0 | captured | 55.604 | 7.815 | 262.677 | 3.00 | -0.788 | 2.940 | 3.043 | 1
2 | 10.00 | 55.297 | 9.750 | 262.000 | 8.0 | captured | 55.604 | 7.815 | 262.677 | 2.00 | +0.677 | 1.960 | 2.073 | 1
3 | 15.00 | 54.237 | 14.533 | 260.000 | 8.0 | captured | 55.604 | 7.815 | 262.677 | 7.00 | +2.677 | 6.856 | 7.360 | 1
4 | 20.00 | 52.764 | 19.204 | 258.000 | 8.0 | captured | 55.604 | 7.815 | 262.677 | 12.00 | +4.677 | 11.739 | 12.636 | 1
5 | 25.00 | 50.889 | 23.730 | 256.536 | 8.0 | captured | 55.604 | 7.815 | 262.677 | 17.00 | +6.141 | 16.599 | 17.698 | 1
6 | 30.00 | 48.627 | 28.075 | 256.000 | 8.0 | captured | 55.604 | 7.815 | 262.677 | 22.00 | +6.677 | 21.428 | 22.444 | 1
7 | 35.00 | 45.995 | 32.206 | 256.000 | 8.0 | captured | 55.604 | 7.815 | 262.677 | 27.00 | +6.677 | 26.216 | 27.053 | 1
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

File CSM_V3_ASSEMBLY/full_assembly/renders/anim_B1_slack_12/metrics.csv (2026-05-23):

frame | theta_cyl_deg | needle_x_mm | needle_y_mm | needle_z_mm | yarn_owner_deg | yarn_state | yarn_x_mm | yarn_y_mm | yarn_z_mm | angular_dist_to_owner_deg | capture_margin_mm | capture_offset_xy_mm | capture_3d_distance_mm | in_capture_window
0 | 0.00 | 56.150 | 0.000 | 264.000 | 0.0 | captured | 56.150 | 0.000 | 252.000 | 0.00 | -12.000 | 0.000 | 12.000 | 1
1 | 5.00 | 55.936 | 4.894 | 263.464 | 0.0 | captured | 56.150 | 0.000 | 252.000 | 5.00 | -11.464 | 4.898 | 12.467 | 1
2 | 10.00 | 55.297 | 9.750 | 262.000 | 0.0 | captured | 56.150 | 0.000 | 252.000 | 10.00 | -10.000 | 9.788 | 13.993 | 1
3 | 15.00 | 54.237 | 14.533 | 260.000 | 0.0 | captured | 56.150 | 0.000 | 252.000 | 15.00 | -8.000 | 14.658 | 16.699 | 1
4 | 20.00 | 52.764 | 19.204 | 258.000 | 0.0 | captured | 56.150 | 0.000 | 252.000 | 20.00 | -6.000 | 19.501 | 20.403 | 1
5 | 25.00 | 50.889 | 23.730 | 256.536 | 0.0 | captured | 56.150 | 0.000 | 252.000 | 25.00 | -4.536 | 24.306 | 24.726 | 1
6 | 30.00 | 48.627 | 28.075 | 256.000 | 0.0 | captured | 56.150 | 0.000 | 252.000 | 30.00 | -4.000 | 29.065 | 29.339 | 1
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

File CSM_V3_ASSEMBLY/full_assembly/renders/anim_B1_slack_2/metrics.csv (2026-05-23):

frame | theta_cyl_deg | needle_x_mm | needle_y_mm | needle_z_mm | yarn_owner_deg | yarn_state | yarn_x_mm | yarn_y_mm | yarn_z_mm | angular_dist_to_owner_deg | capture_margin_mm | capture_offset_xy_mm | capture_3d_distance_mm | in_capture_window
0 | 0.00 | 56.150 | 0.000 | 264.000 | 0.0 | captured | 56.150 | 0.000 | 262.000 | 0.00 | -2.000 | 0.000 | 2.000 | 1
1 | 5.00 | 55.936 | 4.894 | 263.464 | 0.0 | captured | 56.150 | 0.000 | 262.000 | 5.00 | -1.464 | 4.898 | 5.113 | 1
2 | 10.00 | 55.297 | 9.750 | 262.000 | 0.0 | captured | 56.150 | 0.000 | 262.000 | 10.00 | +0.000 | 9.788 | 9.788 | 1
3 | 15.00 | 54.237 | 14.533 | 260.000 | 0.0 | captured | 56.150 | 0.000 | 262.000 | 15.00 | +2.000 | 14.658 | 14.794 | 1
4 | 20.00 | 52.764 | 19.204 | 258.000 | 0.0 | captured | 56.150 | 0.000 | 262.000 | 20.00 | +4.000 | 19.501 | 19.907 | 1
5 | 25.00 | 50.889 | 23.730 | 256.536 | 0.0 | captured | 56.150 | 0.000 | 262.000 | 25.00 | +5.464 | 24.306 | 24.913 | 1
6 | 30.00 | 48.627 | 28.075 | 256.000 | 0.0 | captured | 56.150 | 0.000 | 262.000 | 30.00 | +6.000 | 29.065 | 29.678 | 1
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

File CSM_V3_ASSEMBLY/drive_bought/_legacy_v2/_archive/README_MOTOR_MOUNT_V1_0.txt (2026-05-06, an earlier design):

CSM V3 - NEMA 23 MOTOR MOUNT V1.0
====================================
Date: April 2026

Macro: CSM_V3_MotorMount_V1_0.FCMacro

VERSIONING:
This is V1.0 - the FIRST motor mount design.
Independent version counter per project policy.
Future iterations will be V1.1, V1.2, etc.

PURPOSE:
L-bracket holding NEMA 23 + 5:1 gearbox to 2020 frame.
Belt tension via sliding foot in extrusion channel.

GEOMETRY:
- Motor face plate: 100x100x8mm with NEMA 23 mount pattern
- Foot: 100x50x8mm with 4x slotted M5 holes
- 3x triangular reinforcement ribs at L-corner
- Bounding box: 108 x 100 x 100mm

BELT GEOMETRY (verified):
- 60T HTD 5M cassette pulley (PD 95.49mm)
- 20T HTD 5M motor pulley (PD 31.83mm)
- Belt: 405mm length, 9mm wide
- Calculated nominal center distance: 97.3mm
- Slot adjustment range: 30mm = center distance 82-112mm

HARDWARE - ALL ALREADY OWNED:
- 4x M5 SHCS ~16mm (motor face mounting)
- 4x M5 SHCS ~12mm (foot to T-nut)
- 4x M5 T-nuts for 2020 extrusion
All from existing B0FFSNFK3Y assortment + B0GG4N5GR4 T-nuts.

NO NEW ORDERS REQUIRED.

PRINT SETTINGS:
- PETG, 0.2mm layer, 5 perimeters
- 50% Gyroid infill
- Orient FOOT FACE DOWN on bed
- Supports may be needed under ribs (60deg threshold)
- Estimated print time: 3 hours
- Estimated material: ~150g PETG

INTEGRATION WITH FRAME:
- Bracket bolts to 2020 extrusion via T-nuts
- Slots align with belt tension direction (axis between motor and cassette)
- Slide whole bracket to adjust tension, retighten bolts

VALIDATION TESTS (after install):
1. Verify 20T pulley installed on gearbox output (set screw)
2. Verify belt routes correctly around both pulleys
3. Belt deflection test: 5mm midpoint deflection with 1kg force = correct tension
4. Power motor briefly - smooth rotation, no squeal
5. Run 30 RPM for 10 minutes - check for vibration, heat, click

THIS PART COMPLETES THE DRIVE SYSTEM.
After this, you can test the full motor -> belt -> cassette chain.

NEXT CAD WORK (after this is printed/tested):
- Cassette base V1.0 (if you want to start cassette parts)
- Cylinder R3+ (waiting on needle measurements)
- Yarn guide arm (Phase 4)

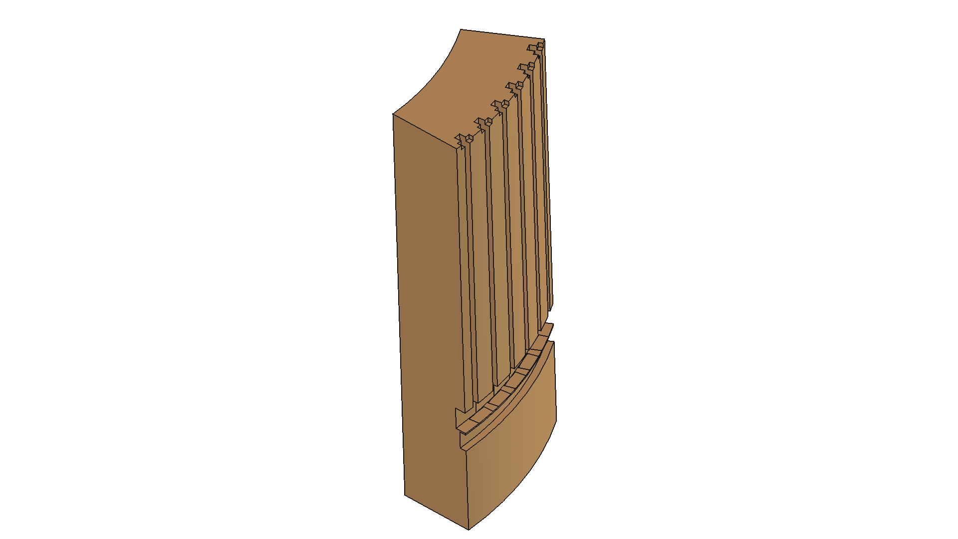
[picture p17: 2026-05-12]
CSM_V3_ASSEMBLY/cassette_head/cylinder/images/Cylinder_V1_1_4_WEDGE_ISO.png

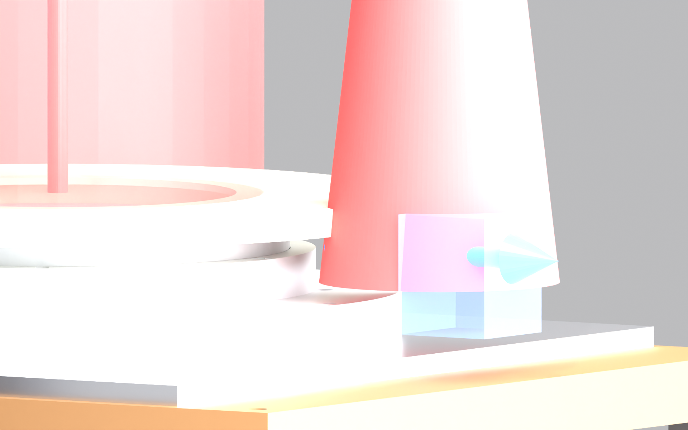
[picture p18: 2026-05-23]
CSM_V3_ASSEMBLY/full_assembly/renders/CSM_V3_AssemblyDrawing_C_triad.png

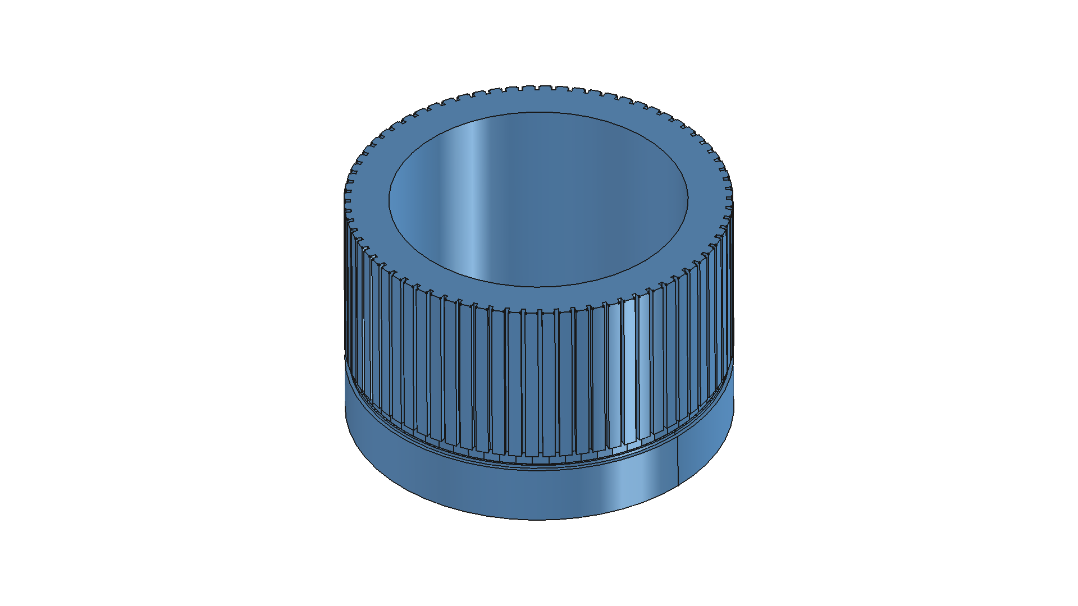
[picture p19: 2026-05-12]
CSM_V3_ASSEMBLY/cassette_head/cylinder/images/Cylinder_V1_1_2_FULL_ISO.png

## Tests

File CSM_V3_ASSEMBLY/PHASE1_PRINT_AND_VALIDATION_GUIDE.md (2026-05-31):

# CSM V3 — Phase 1 Print & Validation Guide

**Status:** Phase 1 bring-up traveler
**Created:** 2026-05-27
**Scope:** Four first-print parts (A, B, D, I) — print, dry-fit, calibrate, record
**Purpose:** Single source of truth for print settings + first-fit measurements.
The measurements captured here drive the next macro revisions (V1.2F, V1.0B, etc.)
and become the project's foundational assembly datums.

> **How to use this doc:** Print it, fill the blank `____` fields at the bench
> with a pen, then transcribe back into this file and commit. Each filled-in
> measurement is a permanent calibration record. Do not delete old values —
> strike them through so the history stays visible.

---

## 0. Part Index & Commit Provenance

| Part | Name | Version | Commit | Macro |
|---|---|---|---|---|
| A | Cassette Spacers (×6) | V1.0 | `33e96e3` | `01_MECHANICAL/02_CASSETTE_HEAD/cassette_spacers/freecad_macros/CSM_V3_CassetteSpacer_V1_0.FCMacro` |
| B | Feeder Module | V1.2E | `5e23e06` | `CSM_V3_ASSEMBLY/feeder_module/freecad_macros/CSM_V3_FeederModule_V1_2E.FCMacro` |
| D | Take-Down Hook Adapter | **V1.0H** (current candidate) + V2.0 (alt., wire hooks) | `dd93e76` … `fa674f6` | V1.0H: `CSM_V3_ASSEMBLY/take_down/freecad_macros/CSM_V3_TakeDownHookAdapter_V1_0H.FCMacro` • V2.0 alt: `…/CSM_V3_TakeDownHookAdapter_V2_0.FCMacro` |
| I | Needle Set & Index Collar | V1.0A | `0850699` | `CSM_V3_ASSEMBLY/needle_jig/freecad_macros/CSM_V3_NeedleSetCollar_V1_0A.FCMacro` |
| SR | Sinker Ring | V1.2.1 (LOCKED, ready to print) | `76fe6f4` | `3D-Project/01_MECHANICAL/02_CASSETTE_HEAD/sinker_ring/freecad_macros/CSM_V3_SinkerRing_V1_2_1.FCMacro` |
| CB | Cassette Base | V1.1 (LOCKED) — **OUTSOURCED, see §1.5** | `b758110` | `3D-Project/01_MECHANICAL/02_CASSETTE_HEAD/cassette_base/freecad_macros/CSM_V3_CassetteBase_V1_1.FCMacro` |
| RR | Retainer Ring | V1.0 (LOCKED) — **OUTSOURCED, see §1.5** | `b758110` | `3D-Project/01_MECHANICAL/02_CASSETTE_HEAD/retainer_ring/freecad_macros/CSM_V3_RetainerRing_V1_0.FCMacro` |
| F | PSU Terminal Guard | **Measurement Required — Not Yet Released** | — | (to be created at `CSM_V3_ASSEMBLY/electronics/psu_guard/`) |

Parts A / B / D / I are **first-print candidates**, NOT production-final.
Part F is **not released** — see §7. Do not print until installed-wiring
measurements are recorded and a final form factor is chosen.

---

## 1. Print Queue Summary

### Recommended print order (risk-stratified)

| # | Part | Practical objective | Why this order |
|---|---|---|---|
| 1 | **D** Take-Down Hook | **Verify printer behavior** | Fast, cheap, no assembly dependency |
| 2 | **A** Cassette Spacers | **Verify dimensional accuracy** | Tiny print, blocks no other work |
| 3 | **I** Needle Collar | **Establish machine datums** | Locks real needle envelope → `NEEDLE_SET_H` |
| 4 | **SR** Sinker Ring (test slices first) | **Verify cassette-ID fit** | Print BOTH dual-clearance test slices (ID115.1 + ID115.3) before the full ring; pick the slice that drops cleanly over the cylinder, then print FULL |
| 5 | **B** Feeder Module | **Verify purchased-component integration** | Print after pigtail dims verified (§2); may go straight to print OR receive a V1.2F update first |

> This sequence mirrors how machine builders normally de-risk a new platform:
> calibrate the printer first, then verify dimensional repeatability, then
> establish the real machine datums, then integrate purchased components
> against those datums.

> Rationale: D and A confirm the printer is dimensionally well-behaved on
> small parts before committing 75 g (I) or 103 g (B) of filament. Part I
> unlocks the needle measurements that may also inform feeder yarn-path
> tuning. Part B is intentionally last so that any pigtail surprise from
> bench measurement can be folded into V1.2F before printing 4–6 hours of
> filament.

### Print settings

| Part | Material | Orientation | Supports | Est. mass | Est. time | Layers / walls / infill |
|---|---|---|---|---|---|---|
| **D** Take-Down Hook | PETG | Ring flat, hooks UP in printer (= DOWN in use) | None | ~19 g | ~45 min | 0.2 / 3 / 30% gyroid |
| **A** Cassette Spacers ×6 | PETG (PA12 prod) | Upright, bore vertical, 6 on bed | None | ~5 g total | ~30 min | 0.2 / 3 / 50% gyroid |
| **I** Needle Collar | PLA or PETG | Datum-hub-down, collar axis vertical | None | ~75 g | ~3–4 h | 0.2 / 3 / 20% |
| **B** Feeder Module | PETG (PA12 prod) | Base flat on bed, block vertical, post tall | None* | ~103 g | ~4–6 h | 0.2 / 3 / 30% |
| **SR** Sinker Ring (test slice) | PETG | Ring flat on bed | None | ~3 g | ~10 min | 0.2 / 3 / 30% |
| **SR** Sinker Ring (full) | PETG (PA12 prod for Phase 2) | Ring flat on bed | None | ~50 g (est) | ~2–3 h | 0.2 / 3 / 30% gyroid |

> **Printer bed constraint:** 230 × 230 nominal, **220 × 220 reliable working area**.
> Any part with footprint > 200 mm has ≤ 10 mm corner margin and is treated as
> bed-marginal (first-layer adhesion risk). Both 200 mm cassette discs are
> therefore **outsourced** — see §1.5 below.

## 1.5 Outsourced Parts (bed-exceeding or bed-marginal)

The two largest Phase 1 parts share **Ø 200 mm OD** (locked to match per ICD R2).
With a 220 × 220 working area both fit, but at the very edge of reliable
adhesion — and these are structural cassette rings where first-layer
delamination would be catastrophic. **Both are sent to an SLS / MJF service
as single pieces** rather than split-and-bond, because:

- Splitting the cassette base cleanly is impractical (pedestal step, register
  pocket, four overlapping bolt-circle patterns intersect at the split line)
- SLS PA12 / MJF PA12 give isotropic strength (no layer-adhesion plane) and
  better dimensional accuracy than FDM at this size class
- Both rings define **datum surfaces** that mate with other locked parts —
  splitting introduces a glued seam at exactly the wrong place

### Parts and upload paths

| Part | STL to upload | File size | Local relative path |
|---|---|---|---|
| **CB** Cassette Base V1.1 | `CSM_V3_CassetteBase_V1_1_FULL.stl` | 7.3 MB | `3D-Project/01_MECHANICAL/02_CASSETTE_HEAD/cassette_base/CSM_V3_CassetteBase_V1_1_FULL.stl` |
| **RR** Retainer Ring V1.0 | `CSM_V3_RetainerRing_V1_0_FULL.stl` | 2.4 MB | `3D-Project/01_MECHANICAL/02_CASSETTE_HEAD/retainer_ring/CSM_V3_RetainerRing_V1_0_FULL.stl` |

### Recommended specification

| Spec | Recommendation | Why |
|---|---|---|
| Material | **PA12 nylon (SLS or MJF)** | Industry-standard structural; isotropic; no layer-adhesion plane; better dim accuracy than FDM at 200 mm scale |
| Color | Natural / white / grey (any) | Cosmetic only; functional surface is internal |
| Finish | Standard / unfinished | Don't pay for vapor smoothing — internal datum surfaces should stay as-printed |
| Tolerance class | Standard (±0.3 mm or service default) | Verify bore + bolt-hole IDs after receipt |
| Quantity | 1 each | No spares yet; revisit after first-fit |

### Approximate cost & lead time (Craftcloud / JLC3DP / Sculpteo / Shapeways)

| Part | PA12 SLS, qty 1 | Lead time inc. shipping |
|---|---|---|
| Retainer Ring V1.0 | $15–25 | 5–10 business days |
| Cassette Base V1.1 | $30–50 | 5–10 business days |
| **Order together** | **$45–75 total** | Save shipping by combining |

Order **both in the same service order** — same shipping, matching production
batch (more consistent tolerances), single receiving event.

### Post-receipt inspection (treat like §1 critical-dimensions)

| Part | Dimension | Nominal | Measured | Pass? |
|---|---|---|---|---|
| CB | Outer disc OD | 200.0 mm | ____ | ☐ |
| CB | Cam-bolt PCD (M5 × 6 at 155 mm) | 155.0 mm | ____ | ☐ |
| CB | Cam-pin PCD (D? × 6 at 145 mm) | 145.0 mm | ____ | ☐ |
| CB | Feeder PCD (M4 × 6 at 190 mm) | 190.0 mm | ____ | ☐ |
| CB | Frame-mount PCD (M5 × 4 at 180 mm) | 180.0 mm | ____ | ☐ |
| CB | Sinker pedestal OD | 150.0 mm | ____ | ☐ |
| CB | Cassette top Z (above frame mount face) | per macro | ____ | ☐ |
| RR | Outer ring OD | 200.0 mm | ____ | ☐ |
| RR | Inner ring ID | per macro | ____ | ☐ |
| RR | Bolt holes align with CB feeder PCD (190) | yes | ☐ | ☐ |
| BOTH | Surfaces flat (no warp from cooling) | < 0.3 mm deviation | ____ | ☐ |
| BOTH | Threads / press-fits test cleanly | go/no-go | ____ | ☐ |

If any dimension is out by more than the service tolerance (±0.3 mm typical),
contact the service for reprint before continuing assembly. The cassette
base + retainer ring fit determines the geometry of every other locked
cassette part — they are the **datum-defining components**.

\* **Feeder post note:** the D15 × 130 mm cone post is the tall, slender feature.
If first-layer adhesion is marginal, add a 5 mm sacrificial raft pad under the
post only. Print times are estimates — confirm in your slicer.

### Critical dimensions to inspect post-print (before assembly)

| Part | Dimension | Nominal | Measured | Pass? |
|---|---|---|---|---|
| A | Spacer length (gap to bridge) | 20.0 mm | ____ | ☐ |
| A | Bore (M4 clearance) | 4.5 mm | ____ | ☐ |
| A | OD | 8.0 mm | ____ | ☐ |
| B | Base plate footprint | 95 × 70 mm | ____ | ☐ |
| B | Mount-hole pitch (PCD-190 chord) | see macro | ____ | ☐ |
| B | Pigtail slot bore | 4.3 mm | ____ | ☐ |
| B | Support-block thickness (T) | 10.0 mm | ____ | ☐ |
| D | Ring OD | 75.0 mm | ____ | ☐ |
| D | Cord-eye bore | 6.0 mm | ____ | ☐ |
| D | Hook tip-to-tip span | (4 hooks @ r33) | ____ | ☐ |
| I | Skirt bore (slip over cyl OD) | 115.10 mm | ____ | ☐ |
| I | Open center | Ø92 mm | ____ | ☐ |
| I | Push-pad height (NEEDLE_SET_H) | 9.0 mm (PROV) | ____ | ☐ |
| SR | Test slice ID — choose fit | 115.3 / 115.1 | _____ wins | ☐ |
| SR | Ring OD | 135.0 mm | ____ | ☐ |
| SR | Ring ID (chosen) | 115.3 mm (nominal) | ____ | ☐ |
| SR | Sinker tip-to-tip span (sample) | ~107.3 mm (2× tip radius) | ____ | ☐ |
| SR | Sample sinker pitch (3 adjacent) | 15.0° / ~14.04 mm arc | ____ | ☐ |
| SR | Drop fit over cylinder (free + smooth?) | yes | ☐ yes ☐ tight ☐ loose | ☐ |
| SR | Sinker base — visible cracks after 24h? | none | ☐ none ☐ hairlines ☐ cracks | ☐ |

---

## 2. First-Fit Inspection Checklist — Feeder Module V1.2E

The feeder yarn-exit clamp has the **most supplier-geometry unknowns**. These
measurements directly drive **V1.2F**.

### Ceramic pigtail (B0FLJK48BB) measurements

| Measurement | Macro assumption | Actual | Notes |
|---|---|---|---|
| Stem thread spec | M4 | ____ | Try an M4 nut: spins free = M4 |
| Usable thread length (sleeve→tip) | ≥ 18 mm | ____ mm | Must clear block T + 2 nuts |
| Jam-nut thickness | 3.2 mm | ____ mm | × 2 nuts |
| Jam-nut A/F (across flats) | 7 mm | ____ mm | |
| Metal sleeve OD | ~6 mm | ____ mm | seats against inboard face |
| Eye offset from stem axis | ~12 mm | ____ mm | sets eye-Z swing range |

### Fit checks (☐ pass / ✗ fail → revision)

- ☐ Pigtail stem passes through slot cleanly (4.3 mm bore OK)
- ☐ Metal sleeve seats **flush** against inboard face (no rocking)
- ☐ Bent neck passes through ridge **center channel** during insertion
- ☐ Both jam nuts reach the outboard face with thread to spare
- ☐ Both jam nuts are wrench-accessible
- ☐ MG90S servo presses into rear cavity, 2× M2 screws align
- ☐ Servo cable exits the cable slot without pinching
- ☐ Base mounts flat to cassette at PCD-190 (M4 holes align)

### Outcome
- Required revision (V1.2F)? ☐ No ☐ Yes → what: ____________________
- Confirmed/changed params for V1.2F: ____________________

---

## 3. Needle Calibration Sheet — Needle Collar V1.0A

**Highest-value measurement section.** This locks `NEEDLE_SET_H`, a foundational
assembly datum that future revisions and the kinematic model depend on.

### Cylinder + needle reference (from MACHINE_DATUMS R5)

| Datum | Value |
|---|---|
| Cylinder OD | 114.30 mm |
| Cylinder top face Z (cyl-local) | 75.0 |
| Hook peak Z at cam lift (cyl-local) | 83.0 (8 mm above top) |
| Slot count / pitch | 72 / 5.0° |
| Slot width | 1.22 mm |
| Needle | FlyDesigns 12g latch |

### Collar fit

- ☐ Collar drops over cylinder OD smoothly (0.8 mm dia clearance)
- ☐ Lead-in chamfer guides blind start
- ☐ Datum hub bottoms on top-face annulus (no rock, seats square)
- ☐ Open Ø92 center gives finger access + bore visibility
- ☐ Wide index notch (slot 0) aligns with θ=0 reference

### Collar fit — measured play (locks future revisions)

The current design gives **0.8 mm diametral clearance**
(cyl OD 114.30, collar bore 115.10). Measure what that actually produces
after PETG/PLA print shrinkage. The result could fix the collar fit
spec for every future revision.

| Measurement | Value | Action if extreme |
|---|---|---|
| Collar rotational free-play on cylinder | ____ ° | <2° = good; >10° = tighten bore |
| Collar radial play at skirt OD (lateral wobble) | ____ mm | <0.3 mm = good; >0.8 mm = tighten |
| Vertical seating drop (held above, dropped, settled at) | ____ mm | should equal datum-hub seat exactly |

**Fit verdict:** ☐ ideal → lock 0.8 mm clear  ☐ tighten → next rev  ☐ loosen → next rev

### THE key measurement

| Measurement | Provisional | **Actual** | Notes |
|---|---|---|---|
| **Hook-tip rest height above cyl top** | — | **____ mm** | with needle seated low/at rest |
| `NEEDLE_SET_H` to set in V1.0B | 9.0 (guess) | **____ mm** | = the measured rest height |
| Latch clearance (latch swings free) | — | ____ | ☐ free ☐ binds |

### Full needle vertical envelope (capture once, save many revisions)

While a needle is installed for the measurement above, also capture the
complete vertical envelope. This data feeds future sinker / cam-profile /
needle-guard / installation-tooling work. Takes one extra minute now —
saves a reinstall later.

| Feature | Z above cyl top (mm) | Notes |
|---|---|---|
| Needle **butt** top | ____ | seats in slot bottom; sets max retract Z |
| Hook **tip** | ____ | same as `NEEDLE_SET_H` measurement above |
| Latch **pivot** (rivet) | ____ | latch swing reference |
| Latch **tip when fully closed** | ____ | upper bound when latch over hook |
| Latch **tip when fully open** | ____ | lower bound when latch out of yarn path |
| Needle butt depth into slot | ____ | (= cyl top Z − butt top Z, signed) |

### SINGLE-NEEDLE PRE-FLIGHT (required before seating all 72)

> Do this **before** dropping all 72 needles. A failure mode discovered with
> one needle costs one needle; with 72 it can damage many. This is the
> single highest-value check in the whole guide.

1. ☐ Insert **one** needle into a slot (preferably the slot 0 reference)
2. ☐ Drop the collar over the cylinder OD and seat it on the datum
3. ☐ Look straight down through the open Ø92 center
4. ☐ Verify the push pad lands on the needle **shank**, NOT on:
   - ☐ hook throat
   - ☐ latch tongue
   - ☐ latch rivet/pivot
   - ☐ needle butt (wrong axial position)
5. ☐ Lift collar off, inspect needle for marks or bend
6. ☐ Try a second slot (180° opposite) to rule out one-off slot variance

**Pre-flight result:** ☐ PASS → proceed to needle freedom test below
                       ☐ FAIL → STOP, record what the pad hit:
                       ____________________ → revision required (V1.0B+)

### Needle freedom test (catches invisible friction damage)

A pad can miss the hook and still lightly scrape the shank. The damage
may be invisible to the eye but will show up as needle friction —
which for a knitting machine is often a more important indicator than
visible marks.

After removing the collar from the single-needle pre-flight above:

- ☐ Needle slides freely through full travel by fingertip
- ☐ No scratch marks visible on needle shank
- ☐ Latch still swings freely after the test
- ☐ Needle returns under gravity when cylinder is held vertical
- ☐ Friction feel matches a fresh (untested) needle from the same batch

If any check fails → STOP, do not populate 72 needles. Revision required.

### Full-population pad contact verification (☐ pass / ✗ fail → revision)

- ☐ Push pads contact needle **shank/back**, NOT hook throat
- ☐ Push pads do NOT touch latch tongues
- ☐ All 72 pads engage; none miss a needle
- ☐ Collar does not rock or bind when seated with needles present
- ☐ Needles end at uniform height after seating
- ☐ Pre-flight (single-needle) test above PASSED before this step

### Outcome
- `NEEDLE_SET_H` locked value: **____ mm** → release **V1.0B "validated"**
- Other params changed: ____________________

---

## 3.5 Take-Down Hook — Failure Mode Diagnostic (REQUIRED before any redesign)

**Context:** During Phase 1 handling, a printed hook stem broke under
light touch. Before iterating on hook geometry (V1.0J / V2.0 / further),
capture the failure data so the next revision targets the real root cause
rather than guessed parameters.

> A 3 mm PETG cantilever printed correctly should feel noticeably **flexible
> before failure**, not snap. "Breaks by touch" most often indicates a
> *print quality* issue, not a *design* issue. Diagnose first.

### What part broke?

- ☐ Take-Down Hook Adapter, version **V1.0F** / **V1.0G** / **V1.0H** ____ (circle one)
- ☐ Other part, name: ____________________

### Fracture location (most informative)

- ☐ At the ring top surface (hook root) → root-fillet stress concentration
- ☐ One layer above the ring → layer adhesion at the first stem layer
- ☐ Midway up the stem → general bending failure
- ☐ At the barb / sphere tip → tip stress riser
- ☐ Multiple locations → systemic print problem

**Photo of fracture (attach to commit, or paste path):** ____________________

> The fracture face tells the story. Photograph at high resolution with
> good light. Layer adhesion failure shows individual layer lines on the
> break face; bulk failure shows a fibrous / matte texture.

### Print parameters

| Parameter | Value | Notes |
|---|---|---|
| PETG brand / batch | ____ | wet PETG = bad layer adhesion |
| Nozzle temperature | ____ °C | PETG ideal ~240-250; below 235 = poor adhesion |
| Bed temperature | ____ °C | typical 70-85 |
| Layer height | ____ mm | 0.2 is standard; 0.28+ = weak |
| Wall count | ____ | **3+ recommended**, 2 walls = too few for small features |
| Infill % | ____ | 30+ |
| Print speed at stem | ____ mm/s | small features need ≤30 mm/s for proper adhesion |
| Part cooling fan at stem | ____ % | PETG **needs less cooling** than PLA; >60% causes layer issues |
| Z-seam position | ____ | random / aligned / sharpest corner |
| Filament dry? | ☐ y ☐ n ☐ unknown | wet PETG = 30-50% strength loss |

### How was the part removed from the bed?

- ☐ Lifted gently after cooling
- ☐ Pried with spatula
- ☐ Flexed off
- ☐ Broke during removal ← important, indicates the break may be a removal artifact not a design failure

### Diagnostic flow

1. ☐ Photograph fracture surface
2. ☐ Fill all print parameter fields above
3. ☐ If wet filament / low temp / over-cooling / 2 walls is the cause →
   **reprint V1.0H** with corrected settings before any geometry change
4. ☐ If fracture at root after correct print → revision needed:
   ☐ **V1.0J** = V1.0H + conical fillet (continuous root fillet, not sphere)
   ☐ **V2.0** = wire-hook carrier (already designed, architectural alternative)
5. ☐ If fracture at stem mid / tip → barb redesign or material change

### V1.0J candidate (conical root fillet) — NOT YET WRITTEN

If diagnostic shows the V1.0H sphere blend is still inadequate at the
root, the next geometry candidate is:

- Replace base-blend sphere (r 2.0) with a **conical frustum**
  - D 6 at ring surface tapering to D 3 over 3 mm of stem height
  - Smooth tangent transition (no curvature discontinuity)
- All other V1.0H params unchanged
- Will not write/run V1.0J until diagnostic data justifies it

### V2.0 status

The V2.0 wire-hook carrier macro and STL **exist in the repo** as an
architectural alternative but are NOT the locked version. They are kept
ready in case post-diagnostic analysis confirms that printed PETG hooks
are fundamentally inadequate. Until then, V1.0H remains the candidate
and Phase 1 plan calls for proving the printed-hook design first, then
switching to wire hooks only if needed.

---

## 4. Take-Down Weight Tuning Table — Hook Adapter V1.0H

Empirical machine-characterization data. Start light, step up 50 g at a time.

| Weight | Yarn | Result | Notes |
|---|---|---|---|
| 250 g | ____ | ☐ missed captures ☐ stable ☐ over-tension | (B1 slack symptom = too light) |
| 300 g | ____ | ☐ missed ☐ stable ☐ over | |
| 350 g | ____ | ☐ missed ☐ stable ☐ over | |
| 400 g | ____ | ☐ missed ☐ stable ☐ over | |
| 450 g | ____ | ☐ missed ☐ stable ☐ over | |
| 500 g | ____ | ☐ missed ☐ stable ☐ over | (D1 stress symptom = too heavy: needle bend / yarn break) |

**Hook adapter fit checks:**
- ☐ 4 hooks engage bottom course evenly (no single-point load)
- ☐ Rounded barbs hold without laddering on removal
- ☐ Cord ties through eye; weight self-centers
- ☐ Ring + weight drop cleanly through D100 take-down column
- ☐ Watch: spider torsional flex on off-axis cord swing — note if excessive

**Optimal Phase 1 window found:** ____ g for ____ yarn

---

## 5. Revision Trigger Notes

Define what justifies a **macro revision** vs. what is **normal tuning**, to
prevent unnecessary CAD churn.

### Normal tuning (NO macro change — adjust in hardware)
- Minor insertion drag on collar or feeder slot
- Take-down weight selection (that's what the table is for)
- Pigtail rotation/tangential position within its adjustment range
- Slight needle height non-uniformity correctable by re-seating

### Geometry revision REQUIRED (bump the macro version)
- Pad hits latch tongue or hook throat → Needle Collar revision
- Pigtail thread is NOT M4, or thread too short for block T → Feeder V1.2F
- Metal sleeve cannot seat flush → Feeder V1.2F
- Bent neck won't pass ridge channel → widen channel, Feeder V1.2F
- Collar rocks/binds on datum (not square) → Needle Collar revision
- Cassette spacer length ≠ 20 mm gap (MD mismatch) → investigate datum, not just part
- Take-down hooks ladder fabric or single-point load → Hook Adapter revision

### Locked-once-measured parameters (update macro, then freeze)
- `NEEDLE_SET_H` (Needle Collar) — from §3
- Pigtail thread spec / block T (Feeder) — from §2
- Take-down weight target (operational, not geometry) — from §4

### Post-bring-up cleanup backlog (non-blocking, do when convenient)

These are known maintainability/refactor items that should NOT be tackled
during bring-up but are tracked here so they don't get lost.

| Item | Trigger | Suggested rev |
|---|---|---|
| Sinker Ring: switch from hardcoded constants to `import machine_datums as MD` | When CYL_OD / SLOT_COUNT next change, OR during any other sinker geometry edit | V1.2.2 |
| Sinker Ring: explicit 0.3 mm base fillets for stress relief | Only if V1.2.1 print shows hairline cracks at sinker root after 24 h (see §1 SR inspection row) | V1.3 |
| Feeder V1.2E: cosmetic "world" vs "cyl-local" label fix in print output | Next feeder revision (functional, not blocking) | V1.2F or later |

---

## 6. Print Orientation Notes

> Screenshots/photos can be pasted under each part as you slice them. Textual
> orientation guidance below is authoritative until images are added.

### A — Cassette Spacers
- **Bed face:** one flat end of the cylinder (bore vertical)
- **Why:** clean straight bore wall, no support in the M4 through-hole
- **Layout:** all 6 standing upright in one print
- **Seam:** anywhere (compression-only part, non-cosmetic)
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

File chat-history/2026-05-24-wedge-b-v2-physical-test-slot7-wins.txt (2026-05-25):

# CSM V3 -- WEDGE_B V2 PHYSICAL TEST RESULT
Date:   2026-05-24
Status: Cylinder V3.0 -> V3.1 locked from physical evidence

================================================================
TEST METHOD
================================================================

Print: CSM_V3_Cylinder_V3_0_WEDGE_B_DEPTH.stl (V2, 10-slot fine sweep)
Material: PETG (Phase 1 prototype filament)
Needles: 12g FlyDesigns latch needles
Procedure: insert needle into each slot, evaluate retention by:
   - axial slide smoothness
   - radial wobble under lateral force
   - spring engagement feel

================================================================
RESULT (slot index left -> right)
================================================================

   slot 6 (4.50 mm depth, 2.90 mm groove)  --  TIE / acceptable fallback
   slot 7 (4.70 mm depth, 3.10 mm groove)  --  BEST -- winner
   slot 8 (4.90 mm depth, 3.30 mm groove)  --  LOOSE -- past the edge

Production lock: slot 7 (4.70 / 3.10).

================================================================
CHANGES PROPAGATED THIS COMMIT
================================================================

(a) CSM_V3_Cylinder_V3_0.FCMacro
    SLOT_DEPTH         3.00  ->  4.70
    SPRING_GROOVE_DEPTH 1.30  ->  3.10
    Output filenames bumped V3_0 -> V3_1
    Header banner V3.0 -> V3.1

(b) machine_datums.py
    SLOT_DEPTH = 4.70  (was 3.00)
    SPRING_GROOVE_DEPTH = 3.10  (was 1.30)

(c) MACHINE_DATUMS.md
    R4 -> R5 with full rationale + physical test evidence

(d) INTERFACE_CONTROL.md
    Locked-versions table: Cylinder V3.0 -> V3.1
    (no ICD revision bump -- architecture unchanged, implementation only)

(e) V3.0 STLs archived to:
    01_MECHANICAL/02_CASSETTE_HEAD/cylinder/_archive/v3_0_locked_2026-05-19/
    Contains: V3_0_FULL, V3_0_WEDGE_A_WIDTH, V3_0_WEDGE_B_DEPTH

(f) V3.1 STLs generated:
    CSM_V3_Cylinder_V3_1_FULL.stl       14.5 MB
    CSM_V3_Cylinder_V3_1_WEDGE_A_WIDTH.stl  2.3 MB
    CSM_V3_Cylinder_V3_1_WEDGE_B_DEPTH.stl  2.4 MB

================================================================
MECHANICAL IMPLICATIONS OF DEEPER SLOT + GROOVE
================================================================

V3.0 (old)                          V3.1 (new)
---------                           ----------
SLOT_DEPTH      = 3.00 mm           SLOT_DEPTH      = 4.70 mm
GROOVE_DEPTH    = 1.30 mm           GROOVE_DEPTH    = 3.10 mm
Slot bottom radius = 54.15 mm       Slot bottom radius = 52.45 mm
Wall remaining   = 10.15 mm         Wall remaining   = 8.45 mm
Spring inner     = 55.85 mm         Spring inner     = 54.05 mm
Needle outer     = 55.95 mm         Needle outer     = 54.25 mm
Spring preload   = +0.10 mm         Spring preload   = +0.20 mm
Spring protrusion = +1.49 mm (past OD)  Spring protrusion = -0.31 mm (RECESSED)

Key wins of V3.1:
 1. Better needle retention (deeper slot grip + 2x preload margin)
 2. Spring no longer protrudes past OD -- no cam ring interference risk
 3. Still 8.45 mm of wall material -- plenty of structural margin

The recessed spring is mechanically SUPERIOR to the V3.0 protruding
spring because:
 - Won't snag on yarn carriers or feeders during rotation
 - Won't foul cam ring inner surface (cam ID 115 - cylinder OD 114.3
   = 0.35 mm/side clearance; V3.0 spring ate ~1.5 mm of that budget)
 - Hidden inside the cylinder profile -- cleaner geometry

================================================================
NEXT STEPS
================================================================

 - Print full Cylinder V3.1 (CSM_V3_Cylinder_V3_1_FULL.stl, ~120 g PETG)
 - This becomes the production cylinder for Phase 1 bring-up
 - All other cassette parts (cam ring, sinker, retainer, cassette base)
   remain unchanged -- the slot/groove change is internal to cylinder only

================================================================

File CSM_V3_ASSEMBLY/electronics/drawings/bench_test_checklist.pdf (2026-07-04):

CSM V3 | BENCH-TEST CHECKLIST
Validate electronics BEFORE installing in machine | Rev V1.0 | ~1-2 h | Page 1: Pre-Test + Stages 1-3
BUILDER: | DATE:

## PRE-TEST SAFETY (REQUIRED)

1. Wall outlet behind a kill switch you can reach without touching the bench.
2. Multimeter ready (DC voltage mode, set to 20 V or 200 V range).
3. No food, drink, or wet items on bench. Dry hands. Insulated mat preferred.
4. E-stop button accessible BEFORE energizing PSU.
5. PSU voltage selector switch matches your wall voltage (115 OR 230 V).
STAGE 1 | PSU ONLY
1. Wire mains: wall | E-stop | 2A fuse | PSU L/N/PE. NOTHING on PSU output.
2. Press E-stop IN. Plug PSU into wall.
3. Release E-stop. PSU green LED should illuminate.

### 4. Multimeter on PSU +V to -V terminals. Reading: ____ V (expect 24.0 ± 0.2 V)

5. Adjust +V trimpot if needed; lock with paint marker once 24.0 V achieved.
6. Press E-stop. PSU LED off within 1 s. Multimeter to 0 V within 2 s.
7. PASS Stage 1: | YES | NO (If NO: check mains wiring, do not proceed)
STAGE 2 | BUCKS + MEGA
1. E-stop IN. Wire Buck #1 IN+/IN- to 24 V bus. Output disconnected.

### 2. Release E-stop. Multimeter on Buck #1 output: ____ V (adjust to 5.10 V)

3. E-stop IN. Wire Buck #1 OUT+/OUT- to Mega VIN + GND.
4. Release E-stop. Mega power LED (ON pin) should light.
5. Connect USB to laptop. Mega should enumerate. Upload Blink sketch.

### 6. LED 13 on Mega blinks at 1 Hz: verified

### 7. Multimeter on Mega 5 V pin to GND: ____ V (expect 4.95-5.10)

8. Press E-stop. Mega LEDs off within 1 s.
9. PASS Stage 2: | YES | NO
STAGE 3 | BUCKS #2 + Pi
1. Repeat Stage 2 procedure for Buck #2. Adjust to 5.10 V no-load.
2. Connect Pi 4 via Buck #2 OUT (or USB-C wall wart for bench test).
3. Pi boots, touchscreen shows desktop within 60 s.
4. Multimeter on Pi 5 V pin to GND under load: ____ V (expect | 5.00)
5. PASS Stage 3: | YES | NO
github.com/leoalex196912/ChatGistory | CSM V3 | Bench-Test Checklist | Page 1 of 2

CSM V3 | BENCH-TEST CHECKLIST
Validate electronics BEFORE installing in machine | Rev V1.0 | ~1-2 h | Page 2: Stages 4-5 + Verdict
BUILDER: | DATE:
STAGE 4 | TB6600 + NEMA 23
1. E-stop IN. Wire TB6600 power (24 V), step/dir/en to Mega D5/D6/D7 via 220 .
2. Wire NEMA 23 4-wire to TB6600 A+/A-/B+/B-.
3. Verify DIP switches: 8 microstep, 2.5 A current limit.
4. Release E-stop. Upload slow-pulse sketch (1 step/100 ms).

### 5. Motor rotates smoothly, no stutter or skipping: verified

6. Listen for grinding or whine. Smooth hum is OK; harsh whine = wrong current.
7. E-stop test: press during rotation. Motor stops within 200 ms.
8. PASS Stage 4: | YES | NO
STAGE 5 | SERVOS (6× MG90S)
1. E-stop IN. Wire ONE MG90S to Mega D9 + Buck #1 5 V rail.
2. Release E-stop. Run sweep sketch (servo position 0-180-0).

### 3. Servo motion clean, no jitter: verified

4. Repeat for servos on D10, D11, D12, D44, D45. All 6 hold position.
5. Combined load test: command all 6 servos to move. Multimeter on Buck #1 output.
6. Voltage stays | 4.95 V during combined motion: ____ V minimum observed
7. PASS Stage 5: | YES | NO
FINAL VERDICT | Bench Test Complete
ALL 5 STAGES PASS | Electronics validated. Proceed to machine integration.
ANY STAGE FAILED | Fix at the bench, NOT in the machine. Re-test.
NOTES / ANOMALIES:
github.com/leoalex196912/ChatGistory | CSM V3 | Bench-Test Checklist | Page 2 of 2

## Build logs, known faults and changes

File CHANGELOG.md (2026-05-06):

# CSM V3 Design Changelog

## Sinker Ring V1.2.1 (May 2026) - CURRENT

**4 Engineering Review Fixes:**
1. Cutter size reduced (prevents adjacent sinker collision)
2. Boolean robustness offset -0.05mm
3. Dual clearance bug fix (CRITICAL)
4. Volume verification added

**Validation:**
- ✅ Test slice printed successfully
- ✅ Angled tip geometry correct
- ✅ Sinker height taper validated
- ✅ Print tolerance 1.4%

## Sinker Ring V1.2 (May 2026)

- All 9 engineering review changes
- 10° backward angled tip (local-frame transformation)
- Dual clearance test slices

## Sinker Ring V1.1 (April 2026)

- 8 of 9 engineering review changes
- Angled tip deferred to V1.2

## Sinker Ring V1.0 (April 2026)

- Initial 72-sinker design
- FLAT tips

---

For technical details, see chat-history/ transcripts.

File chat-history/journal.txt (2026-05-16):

=== Journal Entry 2026-04-21T23:51:51.003606+00:00 ===
2026-04-21-23-51-50-csm-sock-machine-design.txt
[Long-running DIY automated circular sock knitting machine (CSM) engineering design session. Covers complete machine architecture, cassette head geometry, cam ring parametric design with kinematic simulation, FreeCAD macros with auto-export, shopping list request, and cam ring visual diagram request. Contains locked specifications, Python simulation scripts, FreeCAD FCMacro files, SVG blueprints, and Windows batch scripts.]

=== Journal Entry 2026-04-23T00:32:20.963975+00:00 ===
2026-04-23-00-32-20-csm-sock-machine-design.txt
[Long-running DIY automated circular sock knitting machine (CSM V3) engineering design session. Covers complete machine architecture, cassette head geometry with cam ring through 5 iterations (V1→V5 print-ready), kinematic simulation, FreeCAD macros with auto-export, bearing housing blocks, complete shopping list with BOM, and ongoing hardware specification verification (motor, driver, controller, pulleys, shaft collars, yarn components).]

=== Journal Entry 2026-04-23T06:40:38.186289+00:00 ===
2026-04-23-06-40-37-csm-sock-machine-design.txt
[Long-running DIY automated circular sock knitting machine (CSM V3) engineering design session. Covers complete machine architecture, cassette head geometry with cam ring through V5 print-ready iterations, bearing housing blocks, NEMA 23 motor+gearbox selection, HTD 5M belt drive system, ceramic yarn guides, Raspberry Pi 4 electronics, 24V power system, and comprehensive BOM reconciliation with 41 placed orders totaling $888.80.]

=== Journal Entry 2026-04-25T11:59:24.890702+00:00 ===
2026-04-25-11-59-23-csm-sock-machine-design.txt
[Long-running DIY automated circular sock knitting machine (CSM V3) engineering design session. Comprehensive design progression through cam ring V5, bearing housings V1→V2→V2.1→V2.2→V2.3→V2.4 (with deterministic preload via spacer tube), drive hub V2.4→V2.4.1, plus full BOM management across V1-V8 reconciliations. User has placed 57 orders totaling $1,263.84. Contains FreeCAD macros, HTML BOMs with verified ASINs, professional engineering review feedback validation, and Path A architecture decisions for cassette-to-shaft coupling.]

=== Journal Entry 2026-04-25T22:15:27.019844+00:00 ===
2026-04-25-22-15-26-csm-sock-machine-design.txt
[Long-running DIY automated circular sock knitting machine (CSM V3) engineering design session. Comprehensive design progression through cam ring V5, bearing housings V1→V2.4 (deterministic preload via spacer tube), drive hub V1.0→V1.3 (independent versioning), motor mount V1.0→V1.2 (structural upgrade with embedded ribs). User has placed 57 orders totaling $1,263.84. Contains FreeCAD macros, HTML BOMs with verified ASINs, professional engineering review feedback validation, and Path A architecture decisions. Multiple review cycles where reviewer feedback was carefully verified against actual geometry — caught multiple cases where reviewer "fixes" would have introduced bugs (e.g., slot cutting hub in two halves, head pockets making bolts proud, fillet filters too broad).]

=== Journal Entry 2026-04-26T19:18:31.737739+00:00 ===
2026-04-26-19-18-30-csm-sock-machine-design.txt
[Long-running DIY automated circular sock knitting machine (CSM V3) engineering design session. Comprehensive multi-phase design progression: cam ring V5, bearing housings V1→V2.5.1 (now using real Smalley CM25-L1 wave spring with spring-controlled preload), drive hub V1.0→V1.3, motor mount V1.0→V1.3 (structural upgrade with embedded ribs + slot-end relief). User has placed 57 orders totaling $1,263.84. Contains FreeCAD macros, HTML BOMs (V8, V9) with verified ASINs, professional engineering review feedback validation across MULTIPLE review cycles where reviewer feedback was carefully verified against actual geometry — caught many cases where reviewer "fixes" would have introduced bugs. Final session work: redesigned bearing housing V2.5 to use real Smalley CM25-L1 catalog spring (replacing fictional spec from V2.4) and updated BOM V9 with V2.5 hardware needs.]

=== Journal Entry 2026-05-01T01:17:29.649420+00:00 ===
2026-05-01-01-17-28-csm-sock-machine-v3-design.txt
[Long-running DIY automated circular sock knitting machine (CSM V3) engineering design session. Multi-phase design: cam ring V5, bearing housings V2.4→V2.5 (now using real Smalley CM25-L1 wave spring with spring-controlled preload, Smalley CM25-L1 verified from live catalog), drive hub V1.0→V1.3, motor mount V1.0→V1.3 (structural upgrade + slot-end relief). Contains FreeCAD macros, HTML BOMs (V8, V9), professional engineering review feedback. Most recent work: V2.5 bearing housing redesign to use CM25-L1 (25mm bore, 19mm shaft clearance, 35N preload at 3.20mm compression). Macro partially built — functional STL geometry complete, console summary/packaging pending.]

=== Journal Entry 2026-05-02T03:35:23.048387+00:00 ===
2026-05-02-03-35-22-csm-sock-machine-v3-cylinder-cam.txt
[Long-running DIY automated circular sock machine (CSM V3) engineering design session. Architectural pivot from custom 90mm cylinder to Legare/AutoKnitter standard 4.5"/114.3mm 72-slot architecture after needle measurements revealed standard CSM compatibility. Contains FreeCAD macros for cylinder, cam ring, and other knitting components. Multiple iterations driven by reviewer feedback. CRITICAL: V6 cam ring was found to have fundamental geometric error (radial vs axial cam) - V6.1 corrected version JUST BUILT but not yet packaged/delivered. BOM updated to V10 with Legare-compatible components.]

=== Journal Entry 2026-05-02T19:14:16.615692+00:00 ===
2026-05-02-19-14-15-csm-v3-automated-sock-machine.txt
[Long-running DIY automated circular sock machine (CSM V3) engineering design session. Legare/AutoKnitter-compatible architecture (rotating cylinder, stationary cam), 114.3mm/72-slot, 12g latch needles. Contains FreeCAD macros for all knitting components. Session includes: needle butt geometry resolution (closed-loop spring eye confirmed), cylinder spring architecture decisions, multi-feeder (6-feeder future, 2-feeder initial) planning, and architecture confirmation (Legare-compatible motorized, NOT Lonati). Multiple reviewer feedback rounds integrated. BOM at V10.]

=== Journal Entry 2026-05-02T19:21:19.508953+00:00 ===
2026-05-02-19-21-18-csm-v3-automated-sock-machine.txt
[Long-running DIY automated circular sock knitting machine (CSM V3) engineering design session. Legare/AutoKnitter-compatible architecture (rotating cylinder, stationary cam), 114.3mm/72-slot, 12g latch needles. Contains FreeCAD macros for cylinder (through V1.1.1 with spring groove), sinker ring planning, multi-feeder architecture, spring mechanics simulation, wood base sizing, and finishing tool recommendations.]

=== Journal Entry 2026-05-02T19:25:27.866921+00:00 ===
2026-05-02-19-25-27-csm-v3-automated-sock-machine.txt
[Long-running DIY automated circular sock knitting machine (CSM V3) engineering design session. Legare/AutoKnitter-compatible architecture (rotating cylinder, stationary cam), 114.3mm/72-slot, 12g latch needles. Contains FreeCAD macros through Cam Ring V6.2 (corrected axial cam physics), BOM V10 with verified purchase URLs, wood base analysis, reviewer feedback integration, and spring mechanics. Currently designing remaining knitting components (sinker ring next).]

=== Journal Entry 2026-05-04T02:35:54.220759+00:00 ===
2026-05-04-02-35-53-csm-v3-automated-sock-machine.txt
[Long-running DIY automated circular sock knitting machine (CSM V3) engineering design session. Legare/AutoKnitter-compatible architecture (rotating cylinder, stationary cam), 114.3mm/72-slot, 12g latch needles. Contains FreeCAD macros through Cam Ring V6.5 FINAL (smoothstep cam easing, smoothstep-blended top lip, conservative 8mm lift), BOM V11 with MG90S servo upgrade (8×), sinker ring design locked but not yet coded. Multi-reviewer engineering iteration history with accepted/rejected changes documented.]

=== Journal Entry 2026-05-04T02:37:48.322000+00:00 ===
2026-05-04-02-37-47-csm-v3-automated-sock-machine.txt
[Long-running DIY automated circular sock knitting machine (CSM V3) engineering design session. Legare/AutoKnitter-compatible architecture (rotating cylinder, stationary cam), 114.3mm/72-slot, 12g latch needles. Contains FreeCAD macros through Sinker Ring V1.0, BOM V11 with actual Orders.xlsx data ($1,018.83 spent), wave spring and washer sourcing decisions, folder structure clarification session. Multi-reviewer engineering iteration history with accepted/rejected changes documented.]

=== Journal Entry 2026-05-04T02:41:02.807104+00:00 ===
2026-05-04-02-41-02-csm-v3-sinker-ring-engineering.txt
[Multi-session DIY automated circular sock knitting machine (CSM V3) engineering design. Covers Sinker Ring V1.0→V1.1 engineering review iteration, directory structure consolidation to 02_CASSETTE_HEAD, and angled tip geometry analysis with V1.2 plan. Contains FreeCAD macros, BOM, purchasing decisions, and component design history.]

=== Journal Entry 2026-05-16T09:00:00.000000+00:00 ===
2026-05-16-09-00-00-csm-v3-cylinder-v3-engineering-iteration.txt
[Long-running DIY automated circular sock knitting machine (CSM V3) engineering design session. Cylinder V2.0 -> V3.0 reverse-engineering and engineering review iteration. Started with user concern that V2.0 didn't visually match Erlbacher/tru-knit photos, progressed through multiple iterations to a mechanically sound V3.0 ready for prototype printing. Final V3.0 parameters: SLOT_DEPTH=3.4mm, SPRING_GROOVE_DEPTH=1.7mm (0.10mm preload), SLOT_ROOT_FILLET=0.5mm (PETG fatigue prevention), bottom ring with D50 take-down opening + 4x M5 inserts at PCD70/45-deg offset + D6 magnet pocket at PCD95 for Hall sensor indexing, fin tops eased via cutter-flare (FIN_TOP_CHAMFER=0.6mm carved into geometry, not post-process). Wedge test redesigned to vary both slot width AND depth (slots 4-6 test depth flex). Multiple reviewer feedback rounds: some accepted (root fillets, magnet pocket, slot depth reduction), some rejected (inaccurate claims about missing spring groove and inverted cylinder/cam rotation). Materials confirmed against BOM_V11 -- net new spend: $0 (D6x2mm magnets B0F4KS6KV3 in inventory, M5 inserts/screws in B0DPQJ4W3Z + B0FFSNFK3Y). Status: macro complete, awaiting first physical print (test wedge first, ~30-45 min, ~10g PETG).]

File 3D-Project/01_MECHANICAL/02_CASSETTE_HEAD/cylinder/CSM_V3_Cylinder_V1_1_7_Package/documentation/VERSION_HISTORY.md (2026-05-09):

# CSM V3 Cylinder Version History

| Version | Date | Critical Change |
|---|---|---|
| V1.0 | Apr 2026 | Initial 72-slot Legare-compatible design |
| V1.1 | Apr 2026 | Added cylinder spring groove (initially BOTTOM - WRONG) |
| V1.1.1 | Apr 2026 | Refined spring groove geometry (still wrong location) |
| V1.1.2 | May 2026 | Added PNG export to macro (was missing) |
| V1.1.3 | May 2026 | SLOT_CHAMFER 0.4→0.8mm, groove relocation refinement |
| V1.1.4 | May 2026 | SLOT_DEPTH 1.90→2.00mm, batch boolean optimization, wedge widths expanded |
| V1.1.4_VIZ | May 2026 | Added needle visualization (9 needles, 3 lift states) |
| V1.1.5_VIZ | May 2026 | Added FlyDesigns spring visualization (still at bottom - WRONG) |
| V1.1.6 | May 2026 | **CRITICAL FIX**: Spring moved BOTTOM→TOP per Erlbacher reference |
| V1.1.6_VIZ | May 2026 | Visualization updated for top spring |
| **V1.1.7** | **May 2026** | **PRODUCTION-READY**: Z 68→62, depth 1.2→1.8, needle position fix |
| V1.1.7_VIZ | May 2026 | Visualization with all 3 fixes applied |

## Detailed Change Log

### V1.0 → V1.1 (Spring groove added)
- Added groove for FlyDesigns Common Thickness 0.110" spring
- INITIAL POSITION WAS WRONG: placed at bottom near butt cavity
- Reasoning: incorrectly believed spring engaged the butt L-bend
- Reality: spring engages the STEM near the top

### V1.1.1 (Spring geometry refinement)
- SPRING_GROOVE_W: 3.0 → 3.2mm (PETG shrink margin)
- SPRING_GROOVE_DEPTH: 1.5 → 1.2mm (more spring exposed)
- SPRING_GROOVE_Z: refined to 17.9-21.1mm
- Still wrong position (bottom)

### V1.1.2 (PNG export fix)
- Added missing FreeCADGui.saveImage() calls
- 4 PNG renders: full ISO, full TOP, wedge ISO, wedge TOP
- No geometry changes

### V1.1.3 (Engineering review fixes)
- SLOT_CHAMFER: 0.4 → 0.8mm (better visible entry relief)
- Spring groove fixed structural overlap with butt cavity
  - Was 17.9-21.1, now (in V1.1.3 only) 15.5-18.7
- External slot flare REJECTED (kept straight slots per Legare)

### V1.1.4 (Reviewer fixes 2)
- SLOT_DEPTH: 1.90 → 2.00mm (PETG print tolerance)
- Wedge widths: [1.20, 1.20, 1.22, 1.22, 1.25, 1.25] → [1.18, 1.20, 1.22, 1.24, 1.26, 1.28]
- Batch boolean: fuse all cutters before single .cut() operation
- BUTT_DEPTH = SLOT_DEPTH (linked, was 1.90 fixed)

### V1.1.4_VIZ (Visualization with needles)
- 9 needles in 3 lift states (REST/MID/PEAK)
- Each needle has: stem, butt L-bend, hook curve, pivot, latch
- Cylinder set to 30% transparency
- Cross-section view added

### V1.1.5_VIZ (Spring visualization added)
- Added FlyDesigns spring as torus
- Still at BOTTOM groove (Z=15.5-18.7) - WRONG
- User questioned design - "how are needles held without top spring?"

### V1.1.6 (CRITICAL CORRECTION - spring moved to TOP)
- Authoritative reference: Erlbacher Knitting Machines documentation
- Spring is NOT at butt - it's near the top, engaging stems
- Spring groove relocated: Z=15.5-18.7 (bottom) → Z=66.4-69.6 (TOP)
- Bottom groove DELETED (was never correct)
- All 4 needle visualizations updated for new position

### V1.1.7 (Engineering review final fixes)
**Three fixes applied:**

**Fix #1**: Spring Z center 68 → 62mm
- More material above groove (5.4 → 11.4mm)
- Better stem leverage
- Still in classical "below hooks, above cams" zone per Erlbacher

**Fix #2**: Spring groove depth 1.2 → 1.8mm
- Spring protrusion past OD: 1.59 → 0.99mm
- Reduces yarn carrier snag risk
- Still 1.14mm engagement with stem outer edge

**Fix #3**: Needle radial position correction (visualization)
- OLD: NEEDLE_RADIAL_CENTER = CYL_OUTER_R - SLOT_DEPTH/2  (centered)
- NEW: NEEDLE_RADIAL_CENTER = CYL_OUTER_R - SLOT_DEPTH + STEM_D/2 + 0.05 (against back wall)
- Mechanically correct: spring tension pushes stem inward against slot back

## Geometry Comparison Across Versions

| Param | V1.1.4 | V1.1.6 | V1.1.7 |
|---|---|---|---|
| Spring Z center | 17.1mm | 68.0mm | **62.0mm** |
| Spring groove depth | 1.2mm | 1.2mm | **1.8mm** |
| Spring protrusion past OD | 1.59mm | 1.59mm | **0.99mm** |
| Material above groove | 53.9mm | 5.4mm | **11.4mm** |
| Material below groove | 15.5mm | 47.7mm | **37.4mm** |
| Spring engages | (butt - WRONG) | Stem | **Stem** |
| Bottom groove? | Yes (15.5-18.7) | No (deleted) | **No** |

## Status

- V1.0 through V1.1.5_VIZ: SUPERSEDED (wrong spring location)
- V1.1.6: SUPERSEDED (spring too high, groove too shallow)
- **V1.1.7: PRODUCTION-READY** (all engineering review fixes applied)

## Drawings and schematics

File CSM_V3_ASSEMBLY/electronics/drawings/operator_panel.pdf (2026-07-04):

80

100

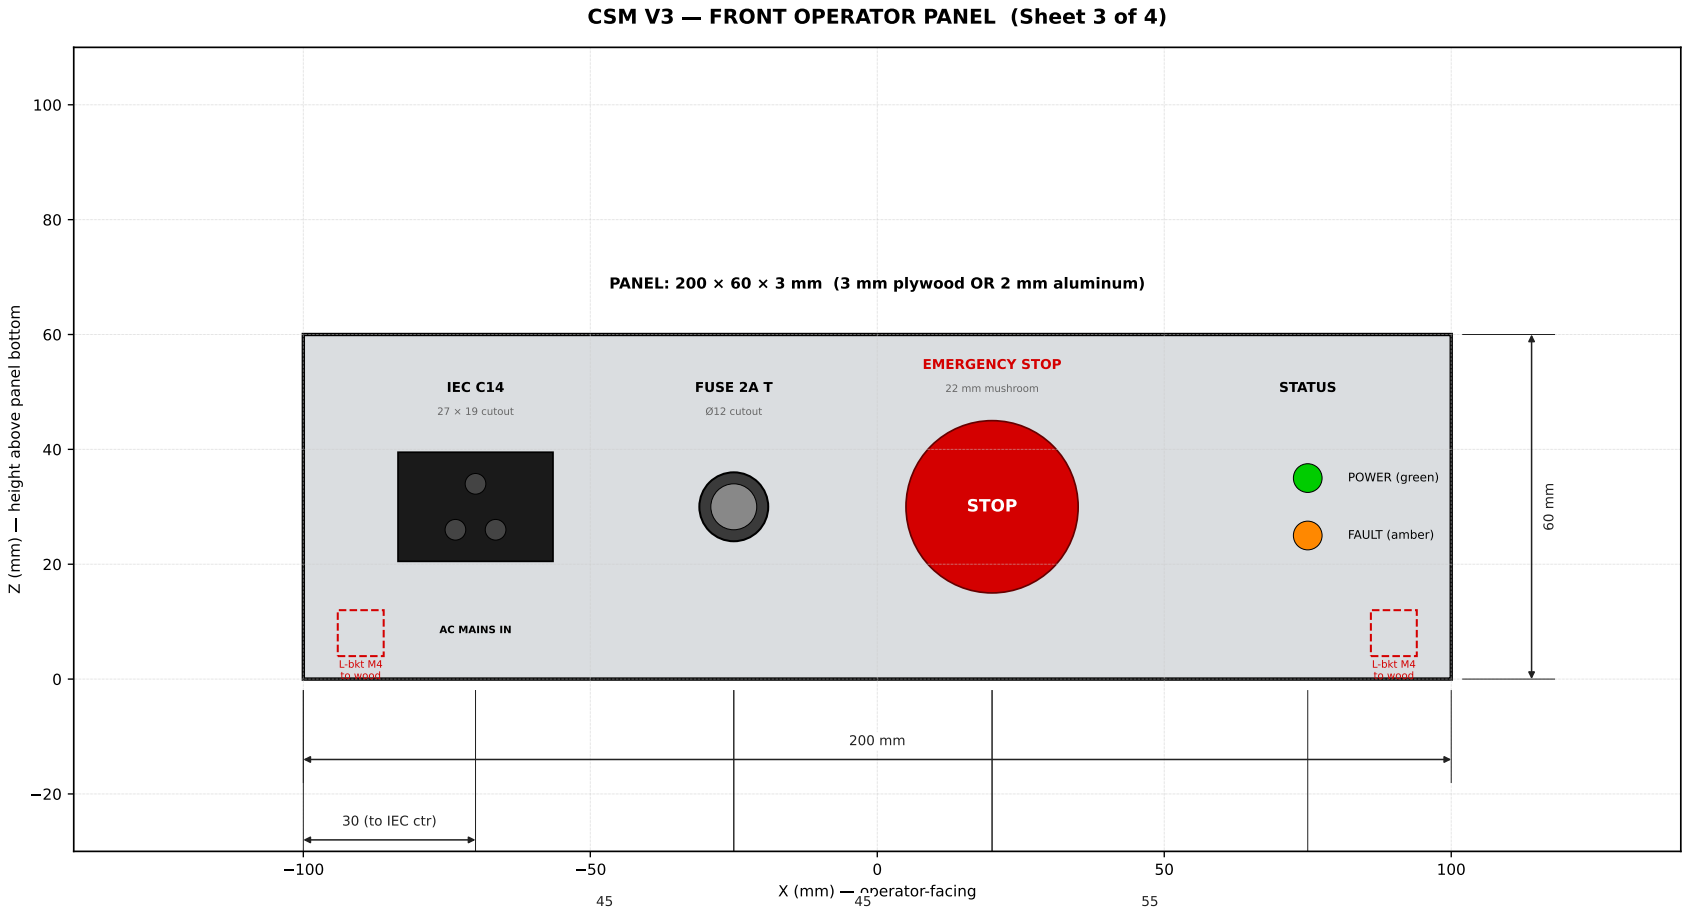
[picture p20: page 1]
operator-facing; CSM V3; FRONT OPERATOR PANEL (Sheet 3 of 4)

PANEL: 200 × 60 × 3 mm (3 mm plywood OR 2 mm aluminum)

Z (mm) height above panel bottom

IEC C14 27 × 19 cutout | FUSE 2A T Ø12 cutout | EMERGENCY STOP 22 mm mushroom | STATUS

STOP | POWER (green) FAULT (amber)

AC MAINS IN L-bkt M4 to wood | | | L-bkt M4 to wood

30 (to IEC ctr)

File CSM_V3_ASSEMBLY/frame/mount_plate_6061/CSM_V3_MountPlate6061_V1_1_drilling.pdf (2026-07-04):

100

150

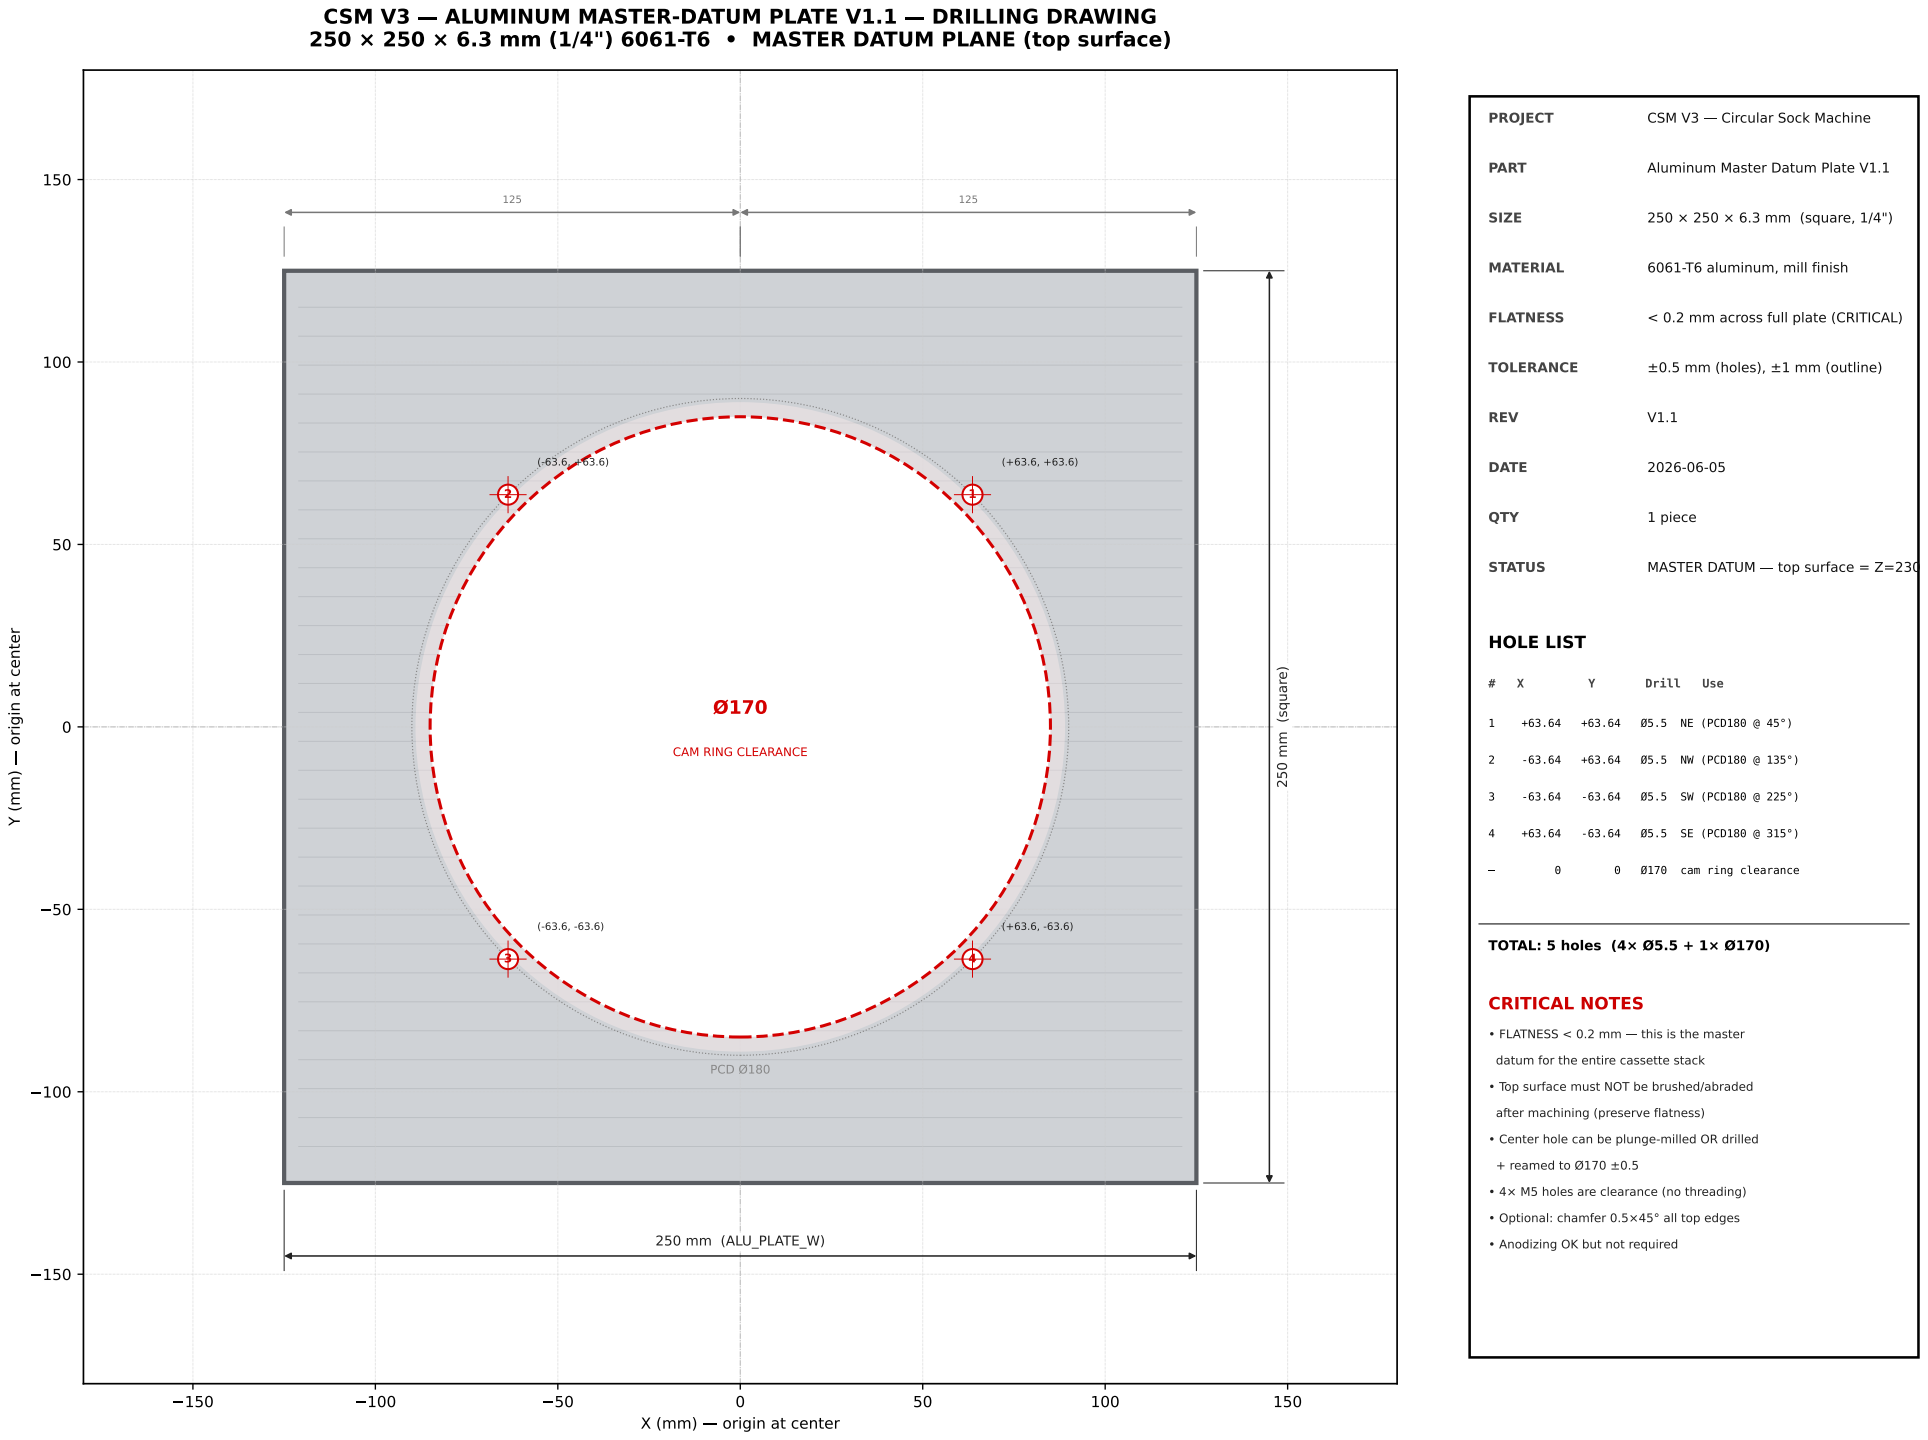
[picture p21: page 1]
origin at center; 250 mm (square); CSM V3; ALUMINUM MASTER-DATUM PLATE V1.1; DRILLING DRAWING; MASTER DATUM PLANE (top surface); PROJECT; Circular Sock Machine; PART; Aluminum Master Datum Plate V1.1; SIZE; 250 × 250 × 6.3 mm (square, 1/4"); MATERIAL; 6061-T6 aluminum, mill finish; FLATNESS; < 0.2 mm across full plate (CRITICAL); TOLERANCE; ±0.5 mm (holes), ±1 mm (outline); REV; DATE; QTY; 1 piece; STATUS; MASTER DATUM; top surface = Z=230; HOLE LIST; Drill; Use; Ø5.5 NE (PCD180 @ 45°)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

Y (mm) origin at center

CAM RING CLEARANCE | DATUM (0, 0)

(-63.6, -63.6) 3 4 | PCD Ø180 | | (+63.6, -63.6)

datum for the entire cassette stack

Top surface must NOT be brushed/abraded

after machining (preserve flatness)

Center hole can be plunge-milled OR drilled

4× M5 holes are clearance (no threading)

Optional: chamfer 0.5×45° all top edges

250 mm (ALU_PLATE_W)

Anodizing OK but not required

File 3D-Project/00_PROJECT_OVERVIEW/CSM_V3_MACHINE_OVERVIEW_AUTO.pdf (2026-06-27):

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

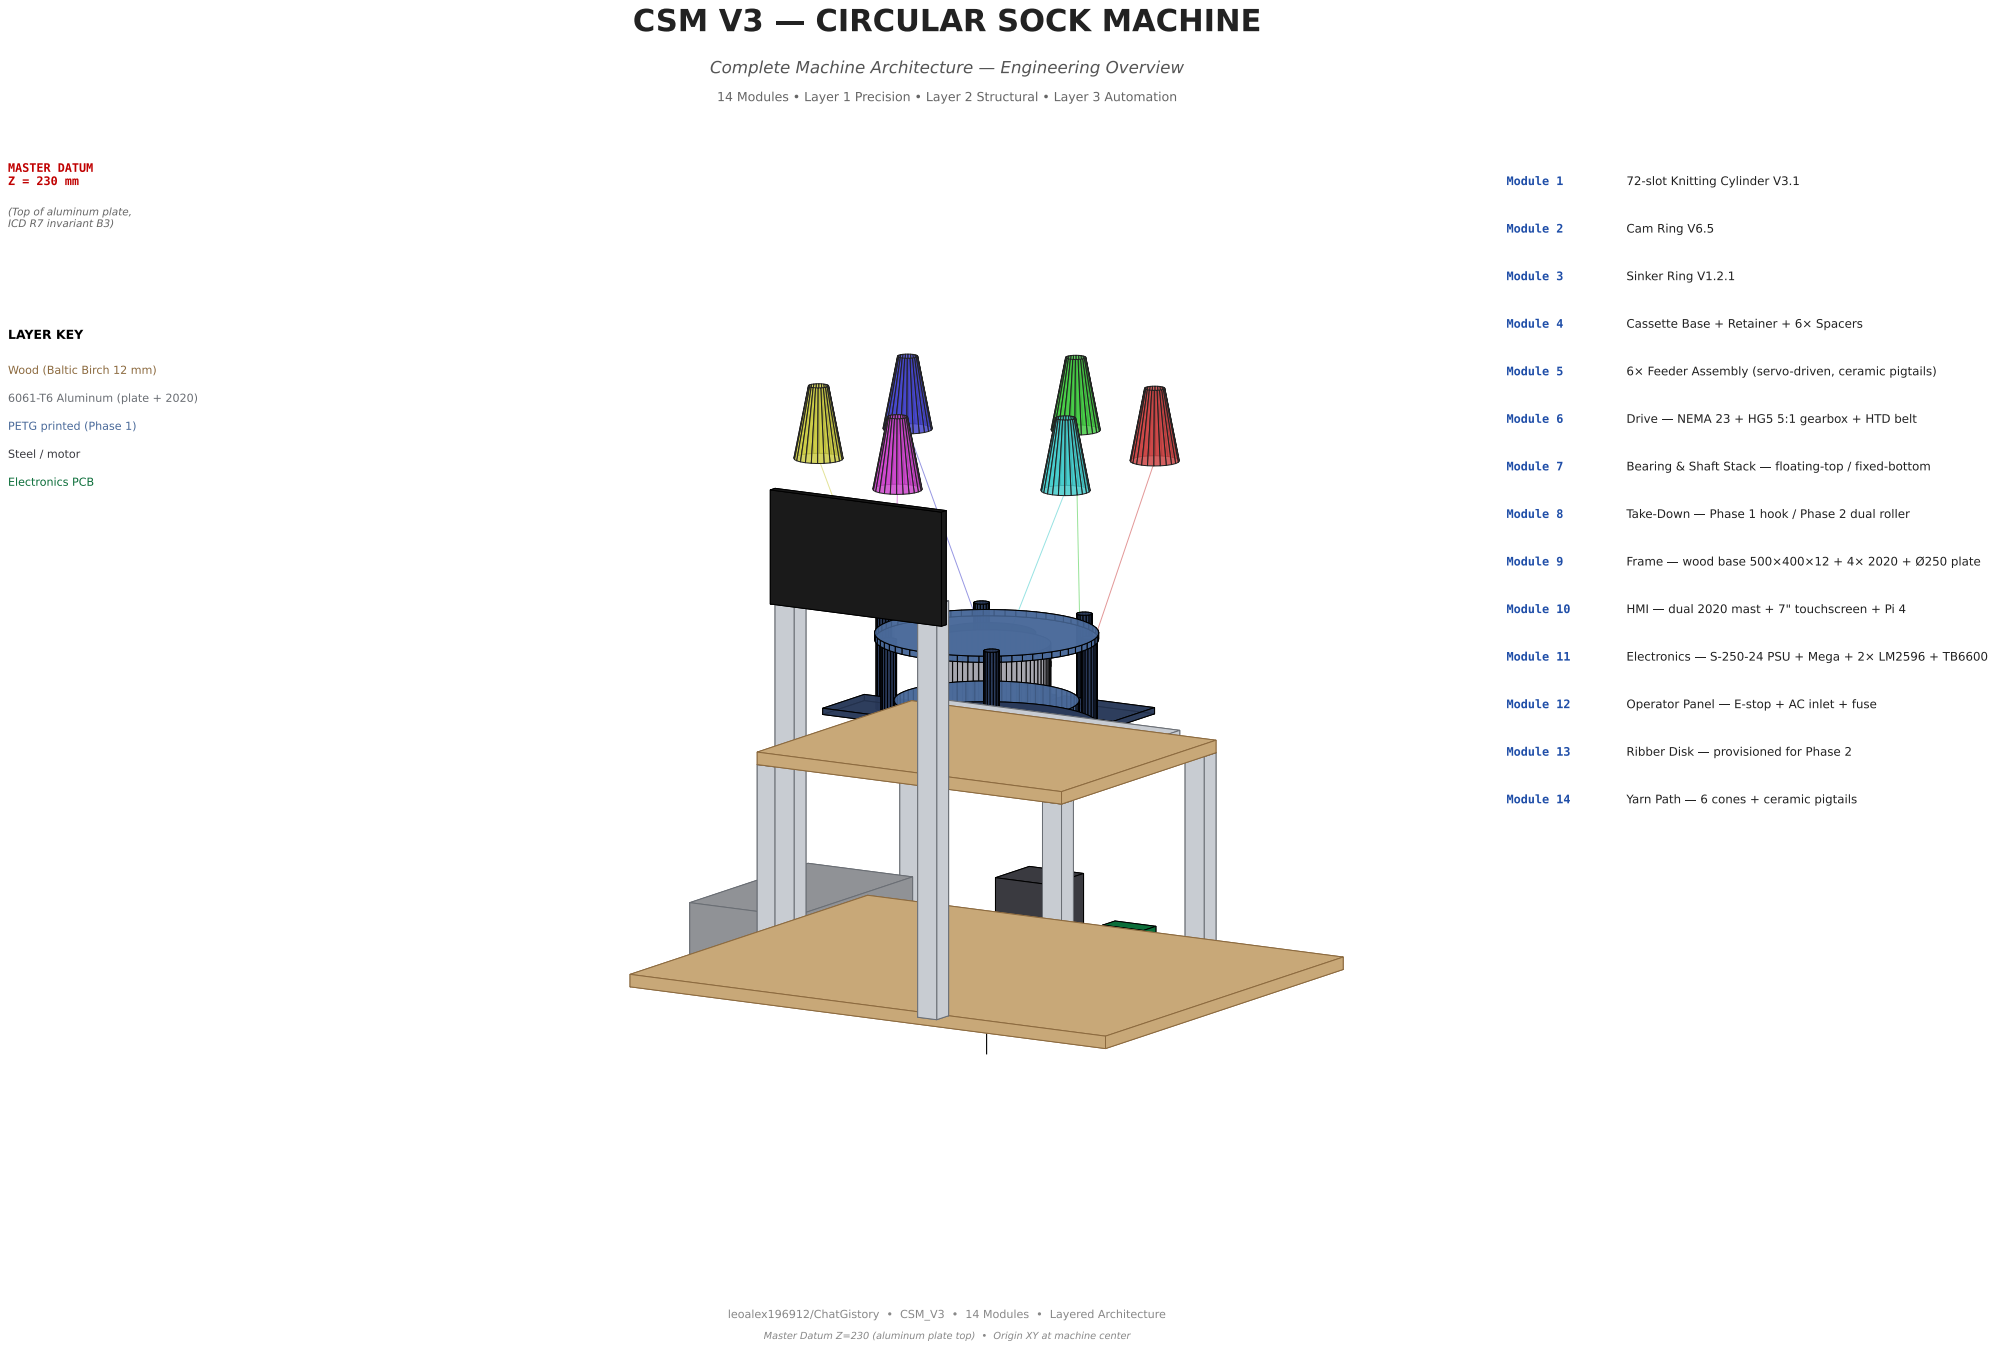
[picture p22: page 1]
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

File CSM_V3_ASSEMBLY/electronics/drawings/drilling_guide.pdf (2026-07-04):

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

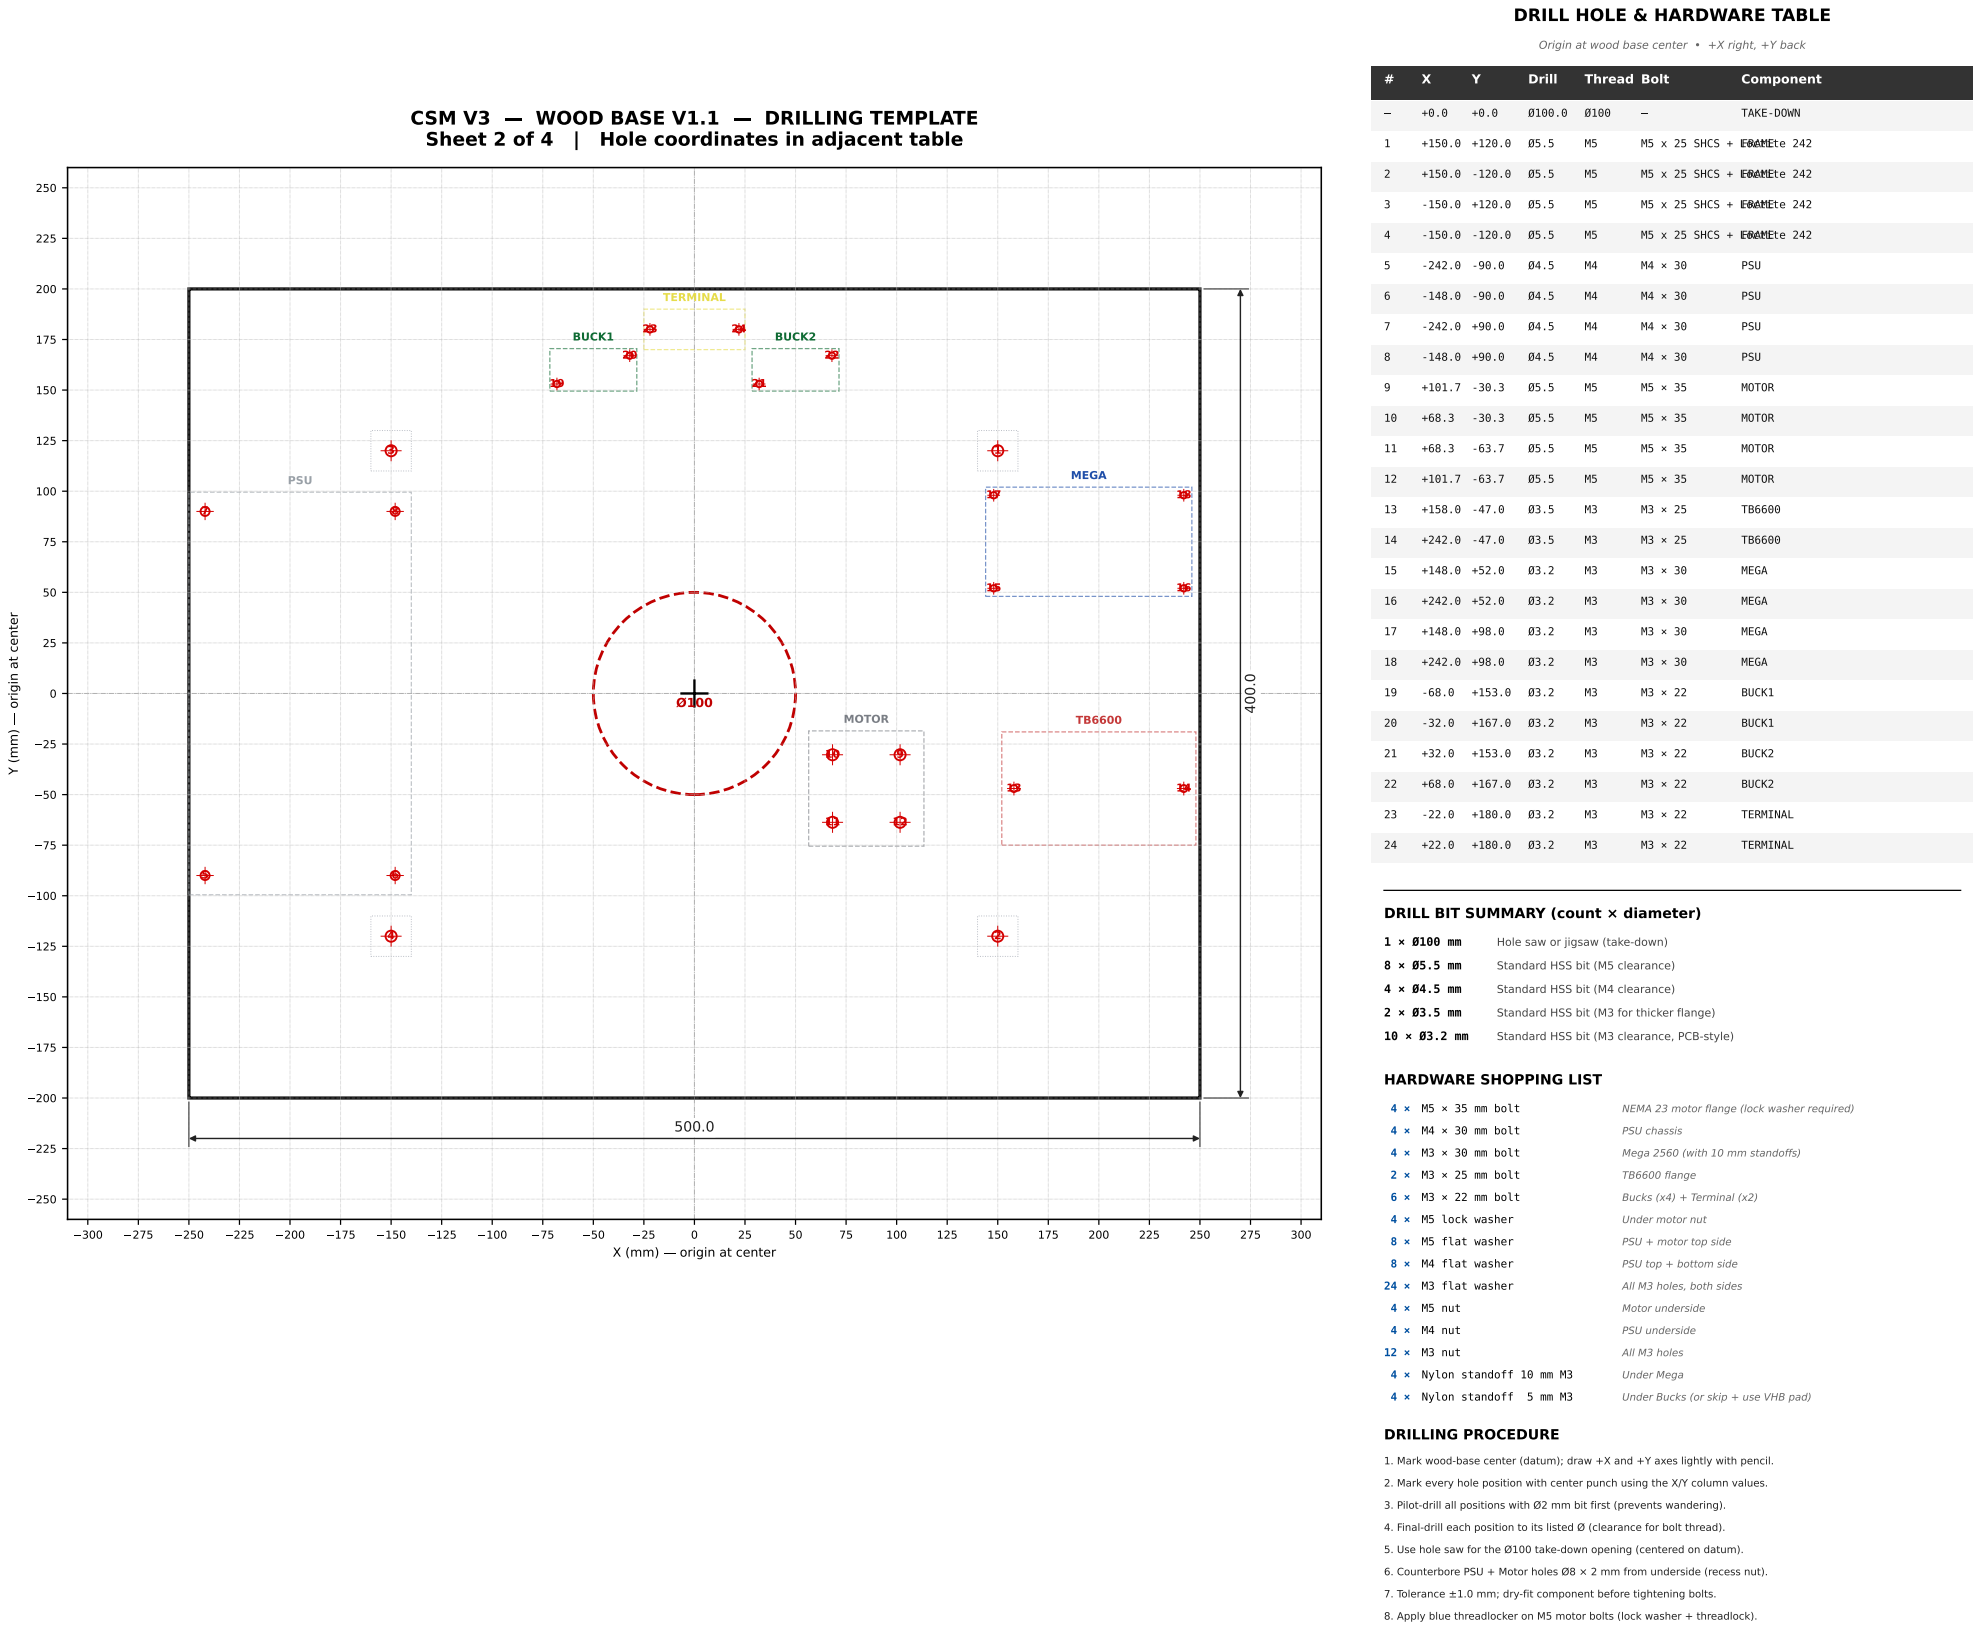
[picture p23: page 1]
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

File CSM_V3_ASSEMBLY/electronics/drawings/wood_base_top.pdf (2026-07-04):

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

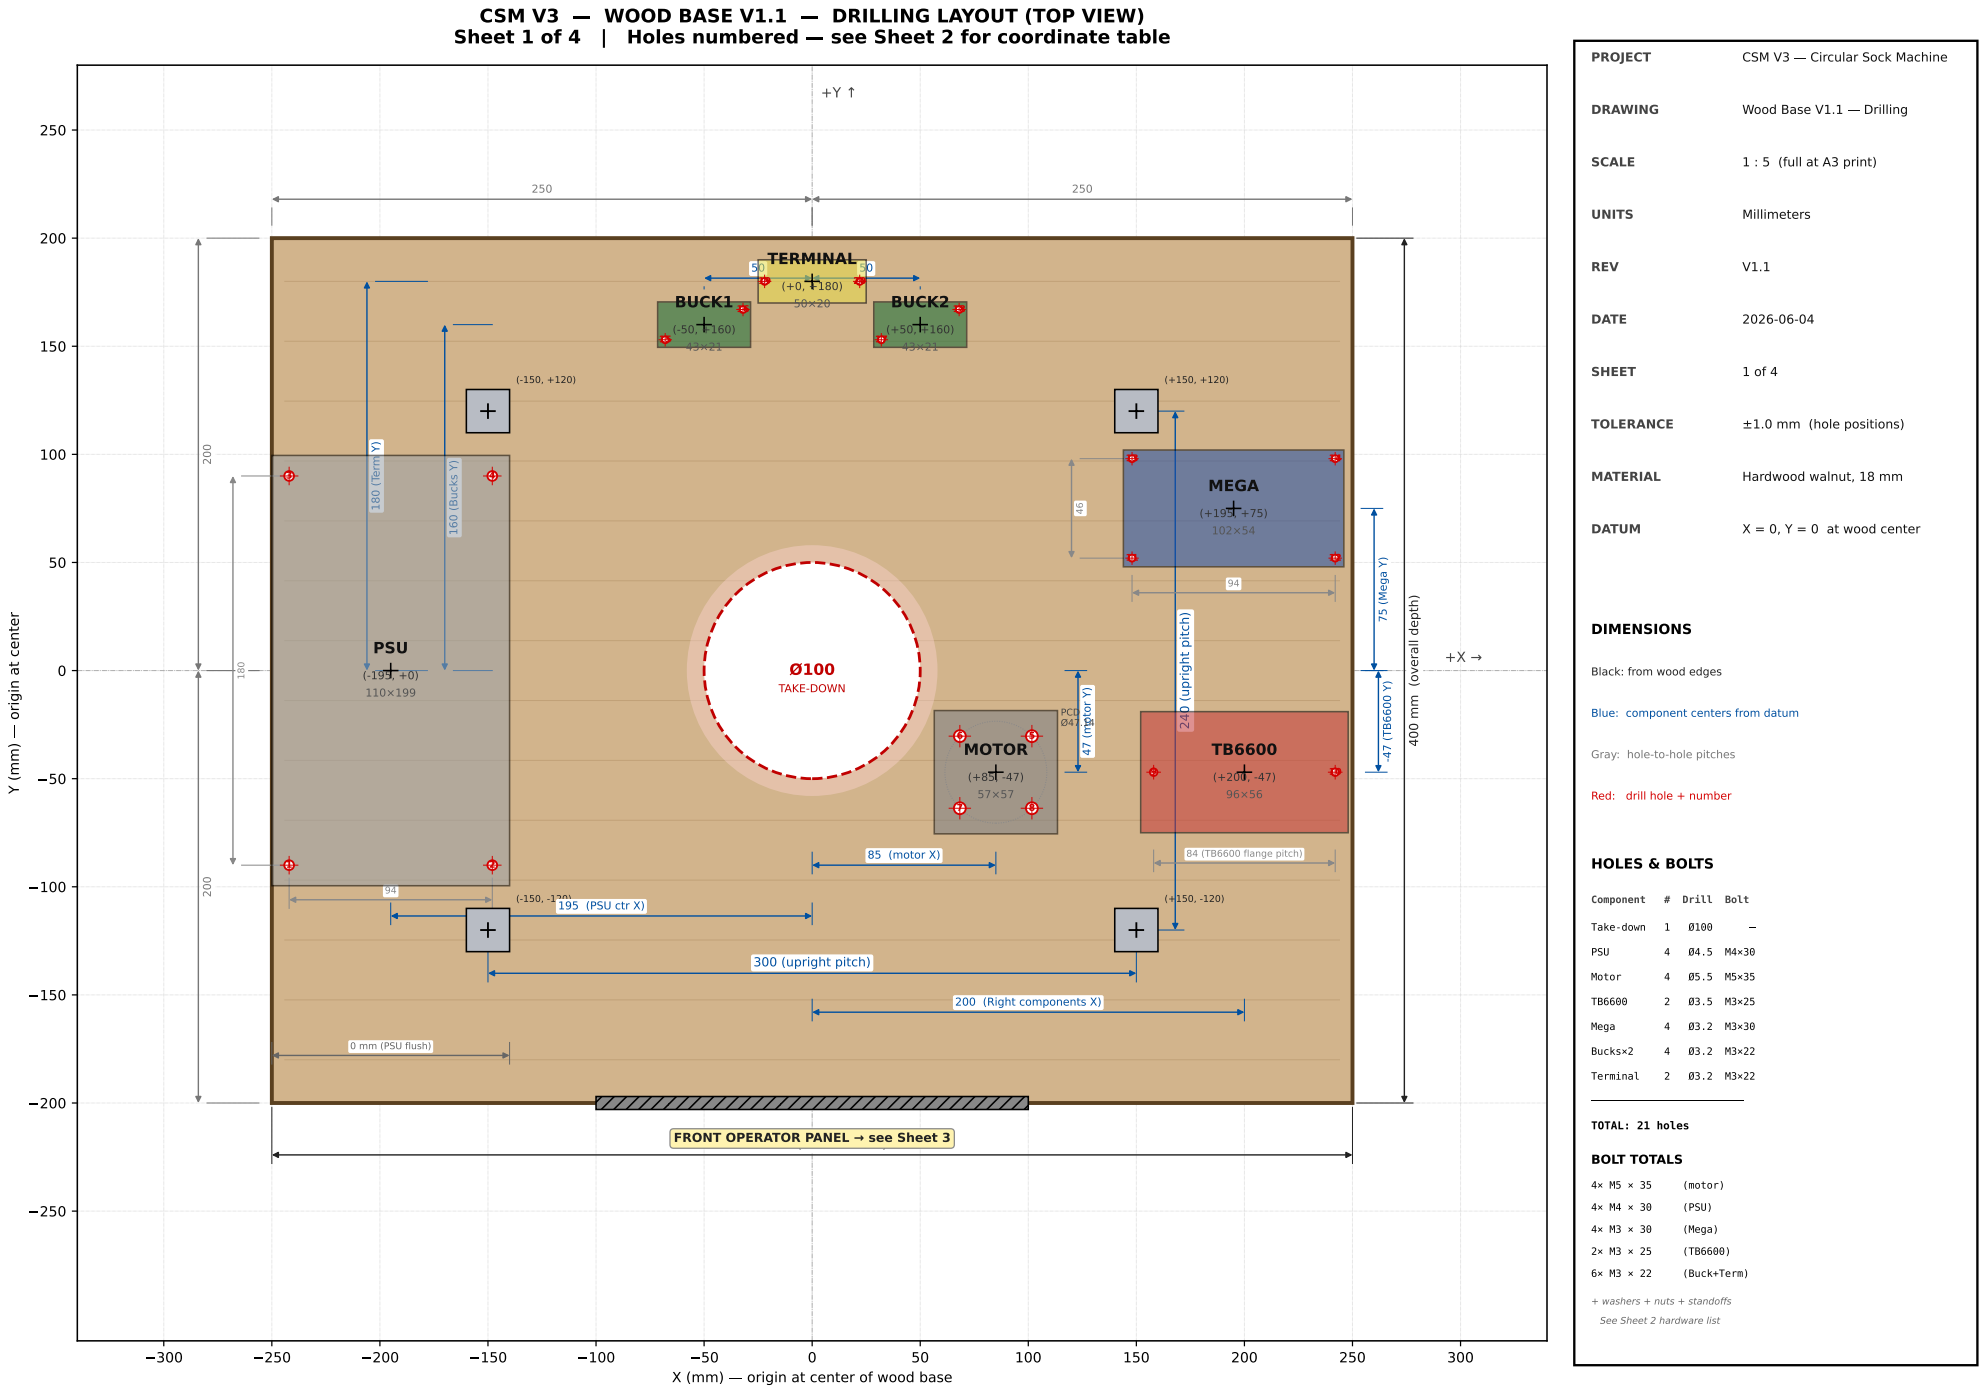
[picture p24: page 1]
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

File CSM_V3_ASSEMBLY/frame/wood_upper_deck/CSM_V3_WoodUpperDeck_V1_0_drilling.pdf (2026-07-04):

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

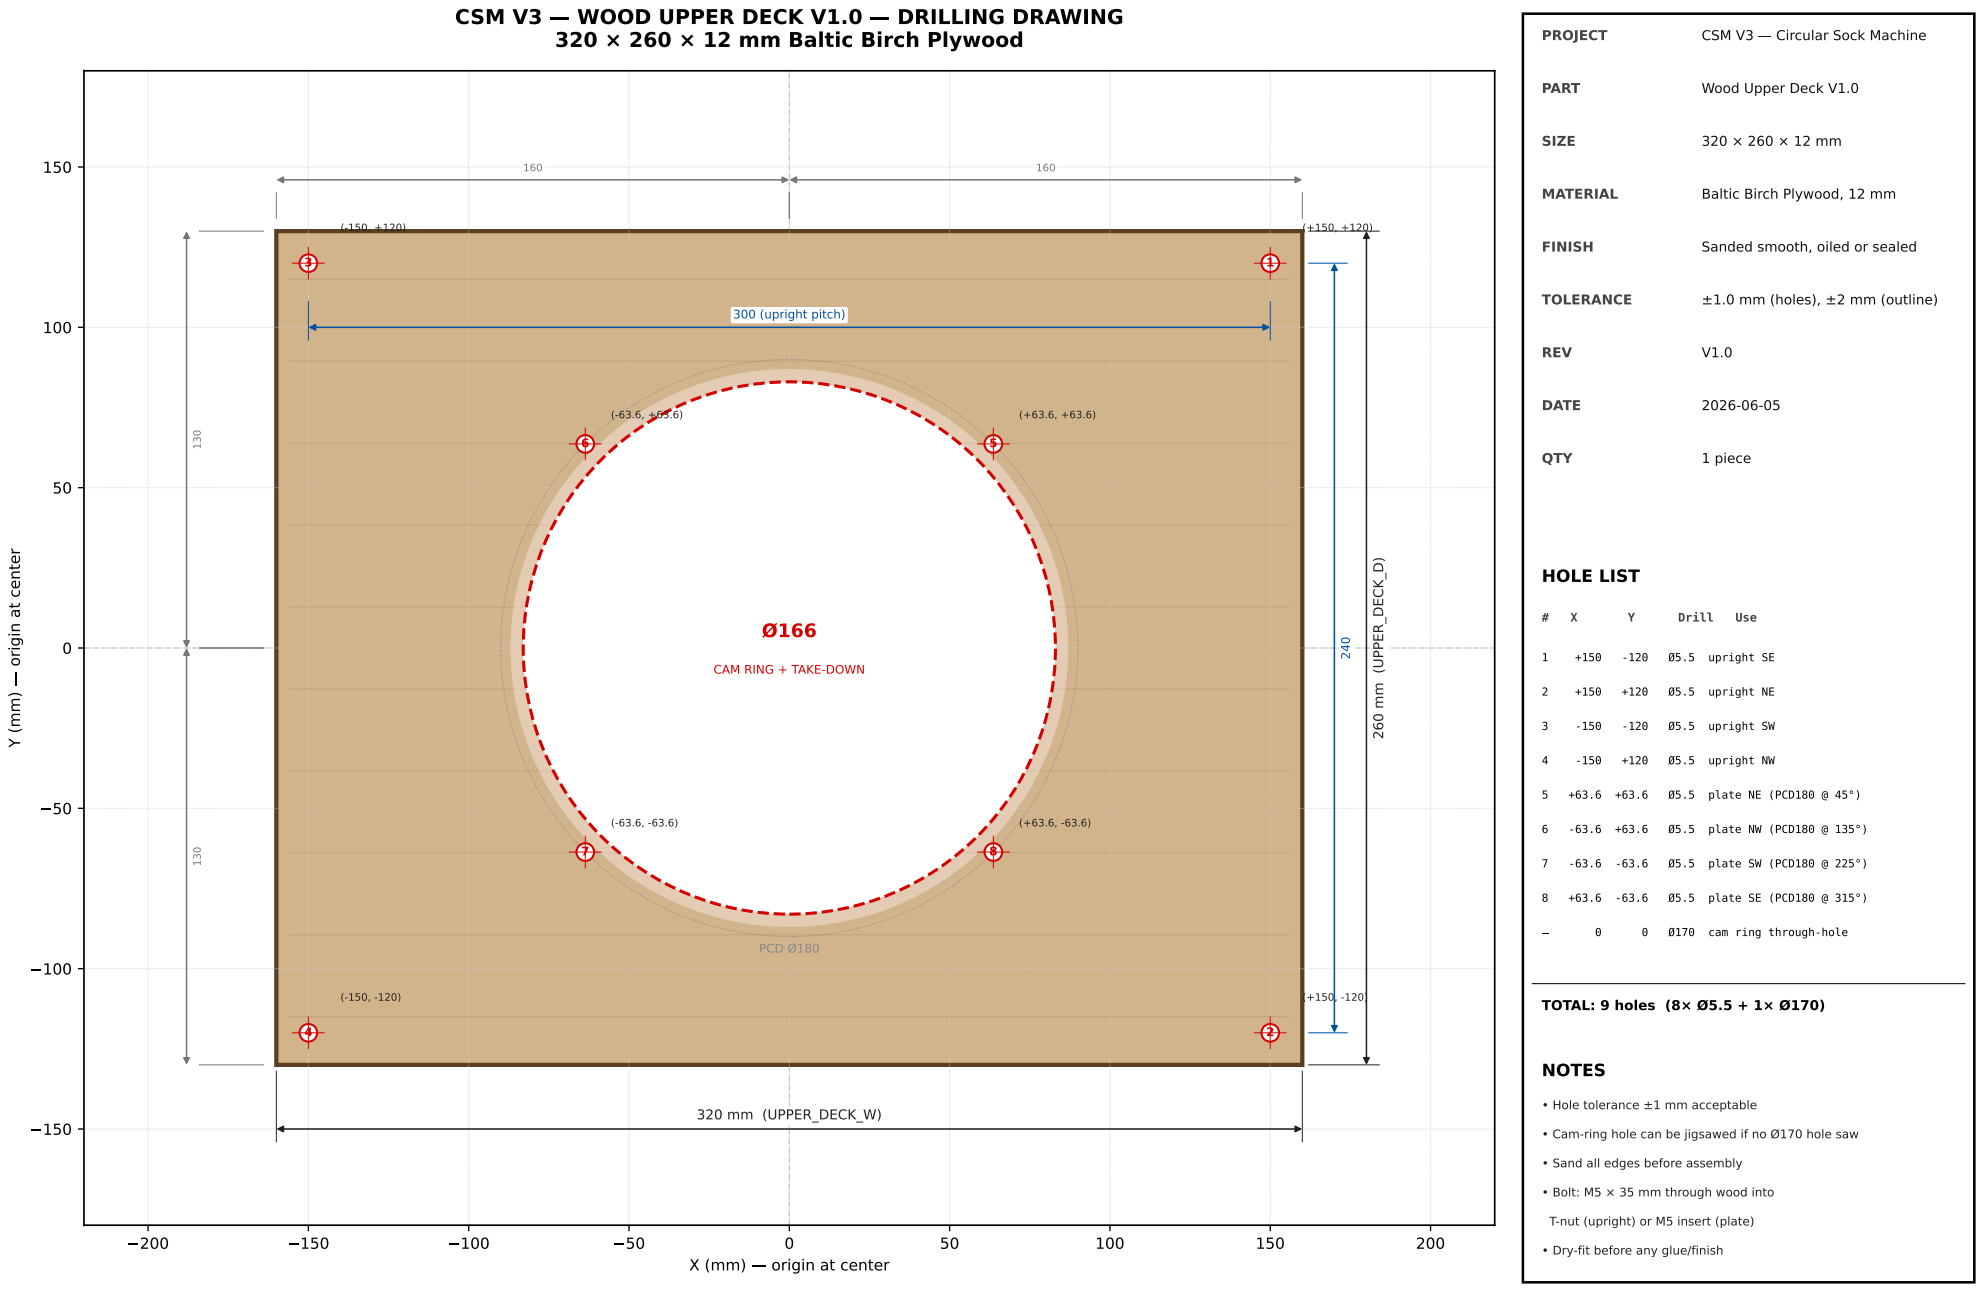
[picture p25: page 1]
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

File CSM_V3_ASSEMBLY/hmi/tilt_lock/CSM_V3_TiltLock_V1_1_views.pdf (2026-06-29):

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

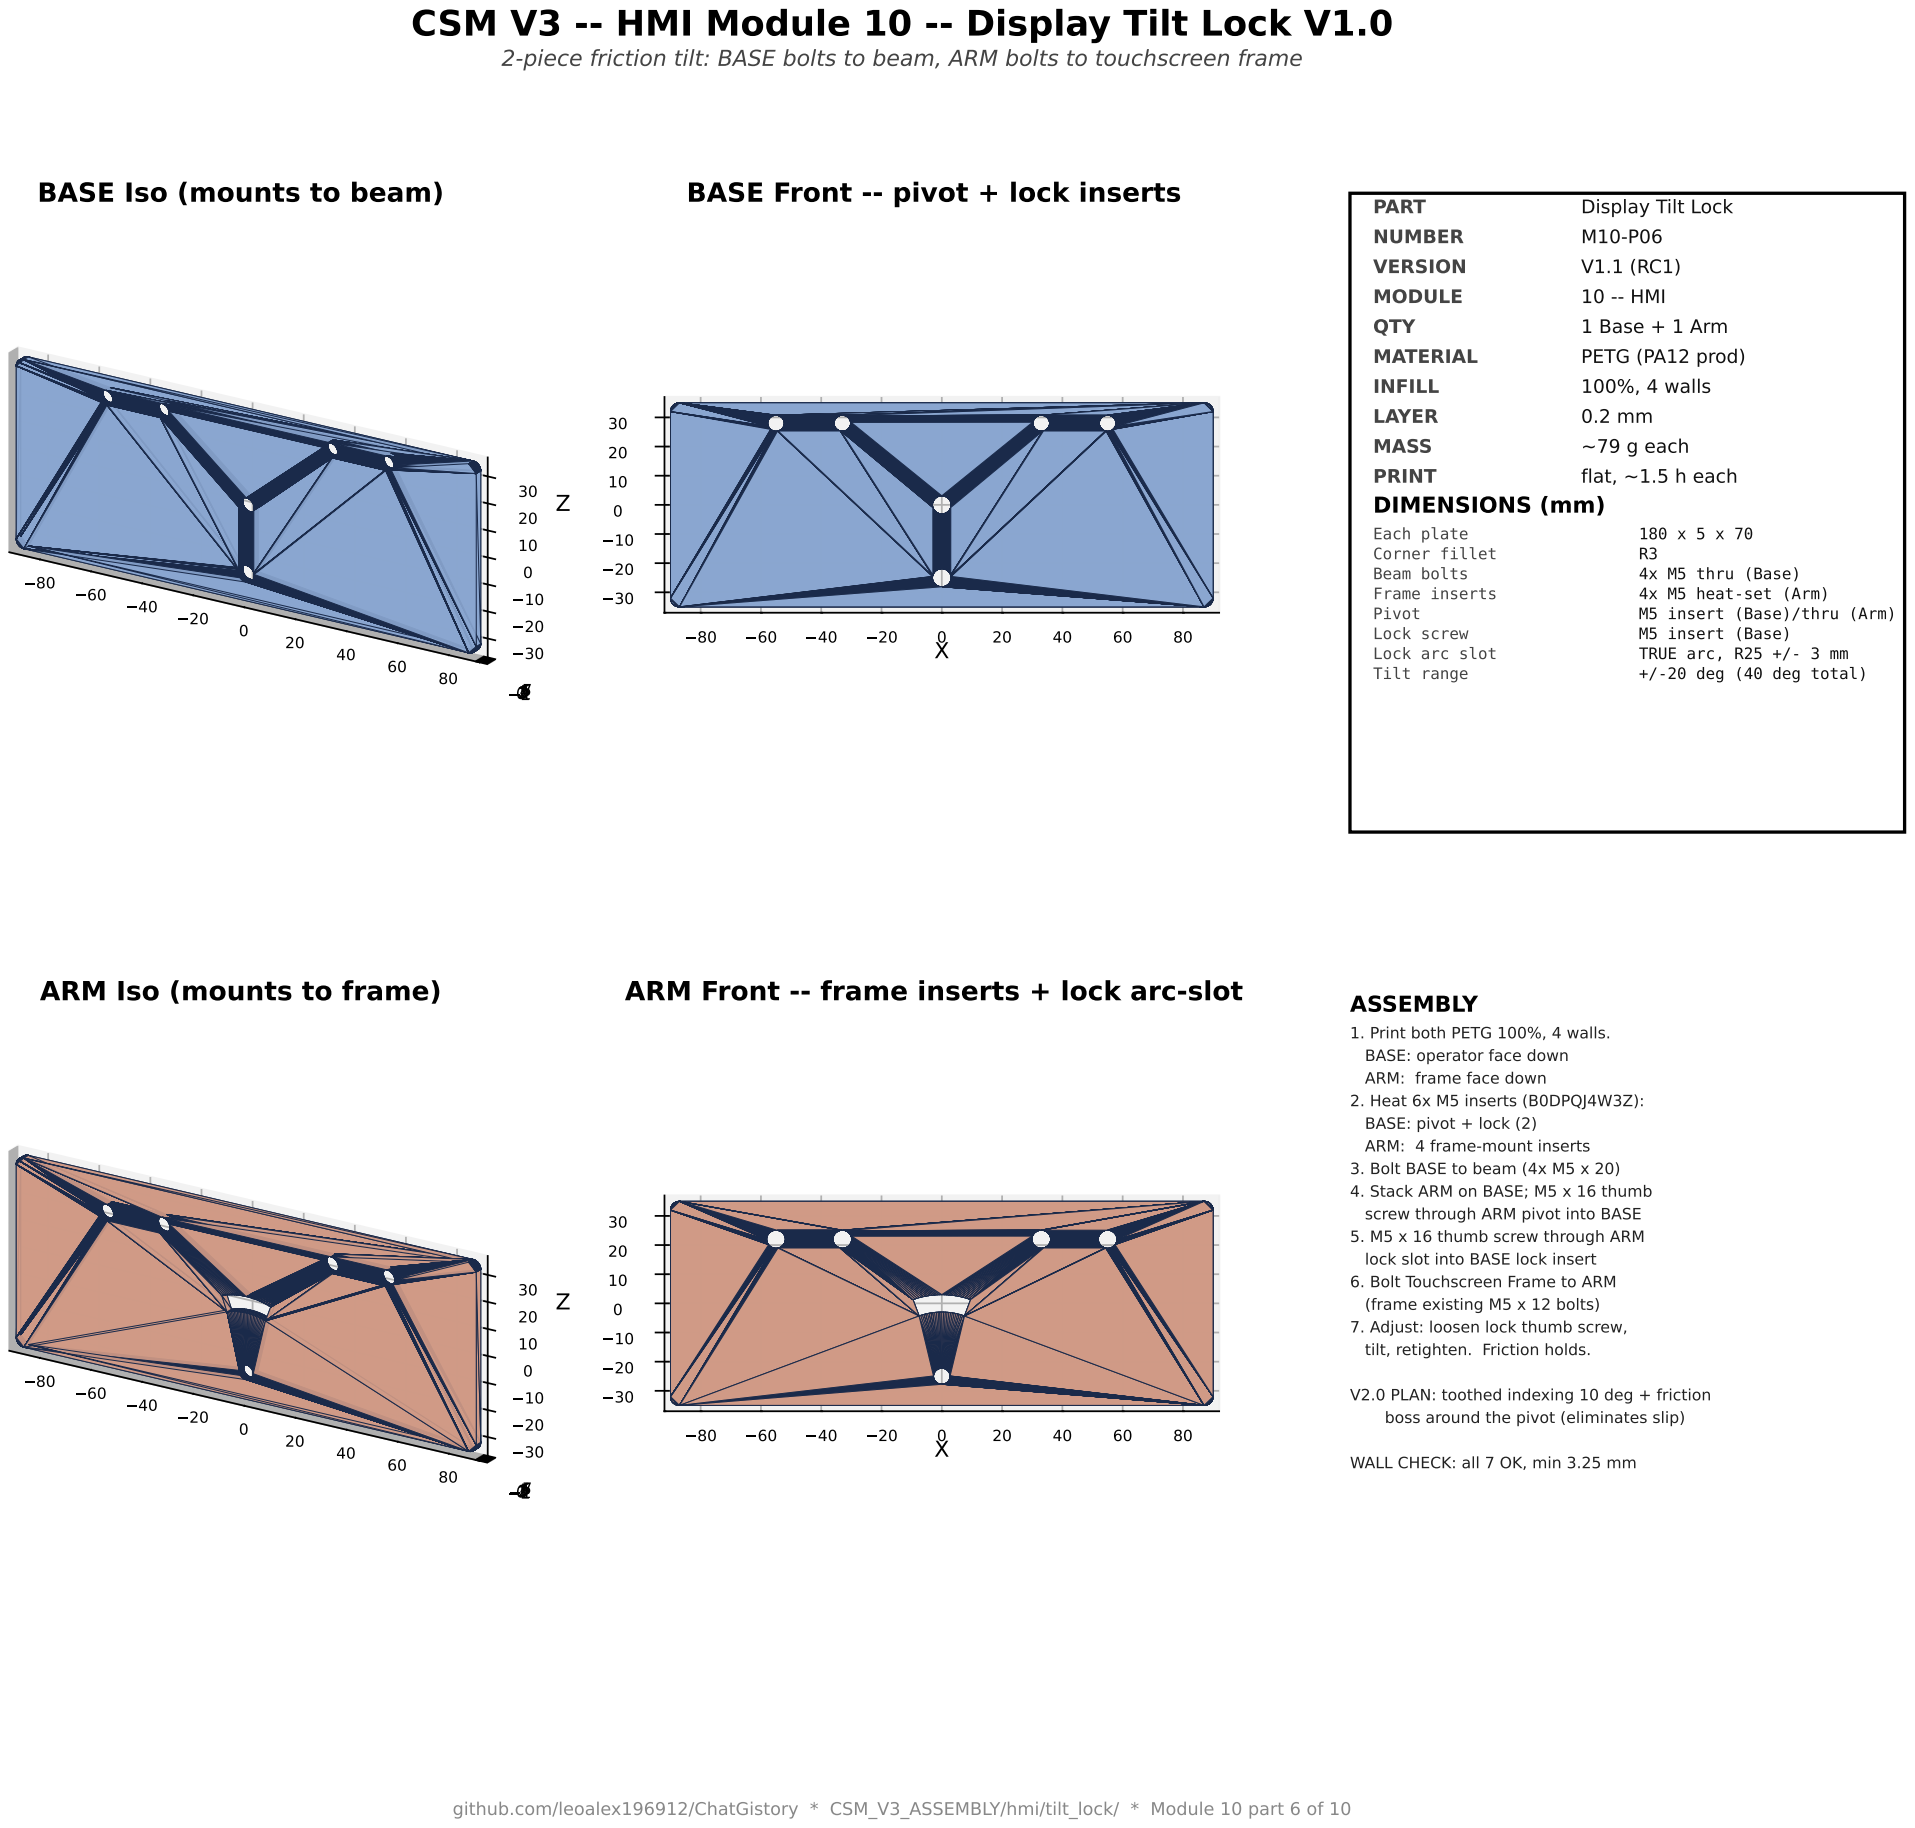
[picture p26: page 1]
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

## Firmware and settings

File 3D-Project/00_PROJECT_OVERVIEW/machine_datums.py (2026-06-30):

# -*- coding: utf-8 -*-
"""
machine_datums.py -- CSM V3 importable constants module

THIS FILE IS THE PYTHON MIRROR OF MACHINE_DATUMS.md (R2 final).
Hand-edit the .md FIRST, then sync this file. Both are tracked in git
and reviewed together. The .md is the human-readable spec; this is
the machine-readable spec.

USAGE
-----
In any FreeCAD macro, Blender script, or assembly utility:

    import sys, os
    sys.path.insert(0, r"C:\\3D-Project\\00_PROJECT_OVERVIEW")
    import machine_datums as MD

    cyl_bottom_world = MD.CYL_BOTTOM_WORLD_Z   # 181.0
    world_z = MD.world_z(MD.CAM_DATUM_Z)       # 230.0

NEVER hardcode world-coordinate numbers in macros or assembly scripts.
Reference MD.<NAME> by name. This is the "no hardcoded world coords"
rule from architecture lock 2026-05-20.

AUTHORITY ORDER
---------------
1. MACHINE_COORDINATE_SYSTEM.md  -- defines axes, origin, transform
2. MACHINE_DATUMS.md             -- defines numerical values
3. machine_datums.py             -- THIS FILE (mirror of #2)
4. component macros              -- import from THIS FILE

If this file and MACHINE_DATUMS.md disagree, the .md wins. Update
this file to match.
"""

# ============================================================
# WORLD <-> CYLINDER-LOCAL TRANSFORM
# (See MACHINE_COORDINATE_SYSTEM.md R1 §4)
# ============================================================
CYL_BOTTOM_WORLD_Z = 181.0   # mm. world Z of cylinder local Z=0
                              # = ALU_PLATE_TOP_Z - CAM_DATUM_Z
                              # = 230 - 49 = 181

def world_z(local_z):
    """Convert cylinder-local Z to world Z."""
    return local_z + CYL_BOTTOM_WORLD_Z

def local_z(world_z_value):
    """Convert world Z to cylinder-local Z."""
    return world_z_value - CYL_BOTTOM_WORLD_Z

# ============================================================
# CYLINDER-LOCAL DATUMS  (from MACHINE_DATUMS.md R2)
# ============================================================
CYLINDER_Z0          =  0.0    # cylinder bottom (= drive hub boss top)
CAM_DATUM_Z          = 49.0    # cam ring top / cassette base bottom
CASSETTE_TOP_Z       = 63.0    # outer disc top of cassette base
SINKER_Z             = 75.0    # sinker register plane
CYLINDER_TOP_Z       = 75.0    # cylinder top face (semantically distinct from SINKER_Z)
FEEDER_REFERENCE_Z   = 90.0    # nominal feeder finger height (provisional, Phase 1.5 validates)
HOOK_PEAK_Z          = 83.0    # needle hook position at peak cam lift

# Derived (DO NOT EDIT DIRECTLY)
HOOK_LIFT            = HOOK_PEAK_Z - CYLINDER_TOP_Z      # 8.0 mm
CASSETTE_DISC_THICK  = CASSETTE_TOP_Z - CAM_DATUM_Z      # 14.0 mm
SINKER_TO_HOOK_GAP   = HOOK_PEAK_Z - SINKER_Z            # 8.0 mm
FEEDER_ABOVE_HOOK    = FEEDER_REFERENCE_Z - HOOK_PEAK_Z  # 7.0 mm

# ============================================================
# CASSETTE GEOMETRY (cylindrical centerlines)
# ============================================================
CYL_OD                  = 114.30
CYL_ID                  =  88.00
SLOT_BOTTOM_RADIUS_DIM  = 107.50   # OD - 2*slot_depth(3.0)
CAM_RING_ID             = 115.00
CAM_RING_OD             = 165.00
CASSETTE_CENTER_HOLE_D  = 117.00
SINKER_PEDESTAL_ID      = 128.00
SINKER_PEDESTAL_OD      = 150.00
SINKER_REG_POCKET_D     = 135.30
SINKER_RING_OD          = 135.00
SINKER_RING_ID          = 115.30
CASSETTE_BASE_OD        = 200.00
RETAINER_OD             = 200.00
RETAINER_THROUGH_BORE   = 118.00
RETAINER_LIP_ID         = 104.00

# ============================================================
# BOLT PATTERNS (PCD = Pitch Circle Diameter, mm)
# All angular offsets are MACHINE FRAME angles (+X axis = 0 deg)
# See ANGULAR_REFERENCE_STANDARD.md R1
# ============================================================
PCD_CAM_BOLTS          = 155.0   # 6x M5, 30 deg offset
PCD_CAM_PINS           = 145.0   # 6x D4 dowels, 0 deg offset
PCD_FEEDER             = 190.0   # 6x M4, 0 deg offset (shared by retainer)
PCD_FRAME_MOUNT        = 180.0   # 4x M5, 45 deg offset
PCD_RIBBER             = 140.0   # 6x M4, 0 deg offset (Phase 2 provision)
PCD_CYL_TO_DRIVE_HUB   =  70.0   # 4x M5, 45 deg offset
PCD_HALL_MAGNET        =  95.0   # 1x D6 magnet, 0 deg

# ============================================================
# FRAME GEOMETRY (world coordinates)
# Origin: cylinder rotation axis projected to Z=0 (wood base bottom)
# See MACHINE_DATUMS.md R2 final
# ============================================================
FRAME_ORIGIN_XY        = (0.0, 0.0)

# Wood base
# Wood thickness 18 -> 12 mm (2026-06-27): user ordered 12 mm Baltic Birch.
# Uprights lengthened 188 -> 200 mm to compensate (cut tolerance absorbs
# the 0.3 mm needed to keep master datum at Z=230 exactly).
WOOD_BASE_W            = 500.0
WOOD_BASE_D            = 400.0
WOOD_BASE_T            =  12.0   # 12 mm Baltic Birch plywood (was 18)
WOOD_BASE_BOTTOM_Z     =   0.0
WOOD_BASE_TOP_Z        =  12.0   # = WOOD_BASE_T
TAKEDOWN_HOLE_D        = 100.0   # ICD Interface 11 (sock take-down column)

# 2020 aluminum uprights (precision frame, 4x at corners of upper deck)
# Practical cut length 200 mm; CAD-exact is 199.7 to land plate top exactly
# at Z=230. 0.3 mm is well within saw kerf / stack tolerance.
UPRIGHT_W              =  20.0
UPRIGHT_LEN            = 199.7   # cut to 200 mm in practice (was 188)
UPRIGHT_BOT_Z          =  12.0   # = WOOD_BASE_TOP_Z
UPRIGHT_TOP_Z          = 211.7   # = UPRIGHT_BOT_Z + UPRIGHT_LEN
UPRIGHT_X_POSITIONS    = (+150.0, -150.0)
UPRIGHT_Y_POSITIONS    = (+120.0, -120.0)

# Wood upper deck (sits on uprights)
UPPER_DECK_W           = 320.0   # X span
UPPER_DECK_D           = 260.0   # Y span
UPPER_DECK_T           =  12.0   # 12 mm Baltic Birch plywood (was 18)
UPPER_DECK_BOTTOM_Z    = 211.7   # = UPRIGHT_TOP_Z (was 206)
UPPER_DECK_TOP_Z       = 223.7   # = UPPER_DECK_BOTTOM_Z + UPPER_DECK_T

# Aluminum master-datum plate
ALU_PLATE_W            = 250.0
ALU_PLATE_D            = 250.0
ALU_PLATE_T            =   6.3    # 1/4" plate (was 6.0 mm — supplier stock)
ALU_PLATE_BOTTOM_Z     = 223.7    # = ALU_PLATE_TOP_Z - ALU_PLATE_T
ALU_PLATE_TOP_Z        = 230.0    # MASTER DATUM PLANE (ICD invariant B3, locked)
ALU_PLATE_MATERIAL     = "6061-T6 mill finish"

# Touchscreen mast (LEGACY -- pre Module-10 lock; do not import in new code)
# These values are kept for backward compatibility with older docs only.
# All NEW HMI code MUST reference the HMI_* block below (ICD R7 Module 10).
MAST_UPRIGHT_LEN       = 400.0
MAST_CENTER_X          =   0.0
MAST_CENTER_Y          = -180.0
MAST_X_OFFSETS         = (+30.0, -30.0)
MAST_TOP_CROSSBAR_LEN  =  60.0
MAST_TOP_Z             = 418.0

# ============================================================
# HMI MODULE 10  (ICD R7 -- locked 2026-06-28)
# Single source of truth for Module 10 (HMI) dimensions.
# Any HMI macro reads constants from this block.
#
# === MODULE 10 HMI INTERFACE LOCK ===========================
# RC1 freeze 2026-06-29.  The interface dimensions below are
# part of the inter-module contract between Module 10 (HMI)
# and downstream consumers (Pi Carrier, Touchscreen Frame,
# Tilt Lock, all accessories).  Do NOT modify any HMI_*
# value without a coordinated update across every macro that
# imports it.  Bump HMI_INTERFACE_VERSION when you do.
#
# Locked interfaces (mechanical contracts between parts):
#   HMI_MAST_X_POSITIONS, HMI_MAST_Y, HMI_MAST_LEN, HMI_EXT_*
#   HMI_SOCKET_OUTER_*, HMI_FOOT_*, HMI_FOOT_BOLT_*
#   HMI_BEAM_LEN_X/W_Y/H_Z, HMI_BEAM_POCKET_DEPTH
#   HMI_PI_MOUNT_PCD_X/Y  (beam-side Pi Carrier mount)
#   HMI_FRONT_INSERT_PITCH (beam FRONT accessory inserts)
#   HMI_PI4_PCD_X/Y       (Pi 4 native footprint)
#   HMI_TOUCH_PCD_X/Y_NOMINAL + HMI_TOUCH_WIN_W/H
#   HMI_TILT_SLOT_R       (tilt-lock pivot-to-lock distance)
#   HMI_INSERT_POCKET_D/H (M5 brass heat-set inserts, BOM
#                          B0DPQJ4W3Z)
# ============================================================
HMI_INTERFACE_VERSION = "1.0"

# Mast placement and stick
HMI_MAST_X_POSITIONS   = (+75.0, -75.0)   # left + right mast centers
HMI_MAST_SPACING_X     = 150.0
HMI_MAST_Y             = -210.0            # wood-base Y of mast feet
HMI_MAST_LEN           = 400.0             # 2020 stick length (cut from 500)

# 2020 extrusion + slip fit
HMI_EXT_W              = 20.0
HMI_EXT_CLEAR          = 0.4               # 0.2 mm per side, FDM slip fit
HMI_POCKET_W           = HMI_EXT_W + 2 * HMI_EXT_CLEAR     # 20.8

# Heat-set inserts (BOM B0DPQJ4W3Z, M5 brass, ~Ø6.4 x 8 mm)
HMI_INSERT_POCKET_D    = 6.2               # press fit (insert OD - 0.2)
HMI_INSERT_POCKET_H    = 8.5

# Foot/beam bolt counterbore for M5 socket-head cap screws
HMI_M5_THROUGH_D       = 5.5
HMI_BOLT_CB_D          = 9.5
HMI_BOLT_CB_H          = 5.5

# Lead-in chamfer at pocket entries
HMI_POCKET_CHAMFER     = 1.0

# === Mast Base Socket V1.3 ===
HMI_SOCKET_OUTER_W     = 34.0
HMI_SOCKET_OUTER_T     = 34.0
HMI_SOCKET_H           = 50.0              # mast engagement
HMI_SOCKET_BOT_T       = 5.0               # closed pocket floor
HMI_SOCKET_POCKET_R    = 1.5               # inner corner fillet
HMI_FOOT_LEN           = 70.0
HMI_FOOT_W             = 54.0
HMI_FOOT_T             = 10.0
HMI_FOOT_BOLT_DX       = 25.0
HMI_FOOT_BOLT_DY       = 19.0
HMI_GUSSET_BASE        = 25.0
HMI_GUSSET_RISE        = 30.0
HMI_GUSSET_T           = 6.0
HMI_FRONT_BOSS_W       = 14.0
HMI_FRONT_BOSS_T       = 4.0
HMI_DRAIN_D            = 3.0

# === Mast Base Socket V1.3 (continued) ===
HMI_RIB_T              = 3.0               # diagonal anti-creep rib thickness
HMI_RIB_H              = 6.0               # rib height above foot
HMI_RIB_OVERLAP        = 4.0               # rib end inside gusset footprint
HMI_T_BOLT_Z1          = 12.0              # lateral 2020 T-nut bolt, low
HMI_T_BOLT_Z2          = 38.0              # lateral 2020 T-nut bolt, high
HMI_EXP_INSERT_COUNT   = 4                 # FRONT-face accessory inserts (socket)
HMI_EXP_INSERT_PITCH   = 20.0
HMI_EXP_INSERT_Z0_REL  = 6.0               # first insert above foot top
HMI_FRONT_BOSS_Z0_REL  = 1.0               # boss starts 1 mm above foot
HMI_FRONT_BOSS_TOP_REL = 5.0               # boss ends N mm below socket top

# === Cross Beam V1.2 ===
HMI_BEAM_LEN_X         = 178.0
HMI_BEAM_W_Y           = 40.0
HMI_BEAM_H_Z           = 30.0
HMI_BEAM_POCKET_DEPTH  = 12.0
HMI_BEAM_END_MARGIN    = 15.0              # cable channel margin each end
HMI_PI_MOUNT_PCD_X     = 58.0              # beam-side Pi Carrier interface
HMI_PI_MOUNT_PCD_Y     = 28.0              # Pi Carrier adapts to Pi 4 58 x 49
HMI_SERVICE_OPEN_X     = 50.0
HMI_SERVICE_OPEN_Y     = 16.0
HMI_CABLE_CH_W         = 8.0
HMI_CABLE_CH_D         = 4.0
HMI_FRONT_INSERT_COUNT = 6                 # FRONT-face accessory inserts (beam)
HMI_FRONT_INSERT_PITCH = 22.0

# === Touchscreen Frame V1.0 (Part M10-P05) ===
# Back plate for ELECROW RC070S 7" touchscreen (Amazon B08FMNDDSL).
# Plate hangs below beam FRONT face; screen attaches via 4 brass pillars
# (included in ELECROW kit) -- M2.5 screws through plate slots into pillars.
HMI_FRAME_W                = 180.0
HMI_FRAME_H                = 130.0
HMI_FRAME_T                = 5.0
HMI_FRAME_TAB_HEIGHT       = 18.0    # band at top with beam-mount bolts
HMI_FRAME_BEAM_BOLT_Z      = 7.0     # bolt center distance from top edge
HMI_FRAME_CABLE_CUT_W      = 30.0    # bottom-edge cable cutout, X width
HMI_FRAME_CABLE_CUT_H      = 10.0    # bottom-edge cable cutout, Z up
HMI_TOUCH_W                = 164.9   # ELECROW RC070S, from official drawing 7inch-D_Size
HMI_TOUCH_H                = 102.0   # (was 165 x 100; corrected from drawing)
HMI_TOUCH_T                = 10.0    # LCD module thickness (front bezel)
HMI_TOUCH_DEPTH_TOTAL      = 34.73   # total depth incl. back PCB (per drawing)
HMI_TOUCH_TOP_MARGIN       = 1.0     # clearance between tab band and screen top
HMI_TOUCH_PCD_X_NOMINAL    = 80.0    # ELECROW mount PCD 79.45 (drawing) -> round 80
HMI_TOUCH_PCD_Y_NOMINAL    = 64.0    # ELECROW mount PCD 64.4 (drawing) -> round 64
HMI_TOUCH_WIN_W            = 30.0    # mount window X (PCD X range 50-110)
HMI_TOUCH_WIN_H            = 30.0    # mount window Z (PCD Y range 34-94)
HMI_M2_5_CLEAR_D           = 3.0     # M2.5 screw clearance hole

# === Expansion Plate V1.0 (Part M10-P10) ===
# Generic accessory plate that bolts to 4 of the 6 cross-beam FRONT-face
# M5 heat-set inserts.  Carries a grid of M3 holes for mounting any
# downstream accessory (sensor PCB, LED driver, label maker, etc.)
HMI_EXP_PLATE_W       = 110.0   # plate X (along beam)
HMI_EXP_PLATE_H       = 70.0    # plate Z (vertical)
HMI_EXP_PLATE_T       = 4.0     # plate thickness (Y)
HMI_EXP_M3_CLEAR_D    = 3.5     # M3 clearance for accessory mounting
HMI_EXP_GRID_PITCH_X  = 20.0    # X spacing of M3 grid
HMI_EXP_GRID_PITCH_Z  = 20.0    # Z spacing of M3 grid
HMI_EXP_GRID_COLS     = 5       # 5 columns of M3 (X = -40 .. +40)
HMI_EXP_GRID_ROWS     = 3       # 3 rows of M3
HMI_EXP_BEAM_BOLT_Z   = 7.0     # M5 bolt center distance from top edge
                                  # (7 leaves 3.5 mm clear to top M3 row;
                                  # 10 only left 0.5 mm)
HMI_EXP_CORNER_R      = 3.0     # plate corner fillet

# === LED Strip Holder V1.0 (Part M10-P09) ===
# Long thin channel that zip-ties to the cross beam underside, carrying a
# 5 V LED strip (10 x 2-3 mm) pointing down for cassette work-area lighting.
HMI_LED_HOLDER_L         = 150.0  # X length (less than beam 178 mm)
HMI_LED_HOLDER_W         = 14.0   # Y width
HMI_LED_HOLDER_H         = 5.0    # Z thickness
HMI_LED_STRIP_W          = 10.0   # LED strip cavity width
HMI_LED_STRIP_H          = 2.5    # LED strip cavity depth (into bottom face)
HMI_LED_TIE_GROOVE_W     = 4.0    # zip-tie groove width (X)
HMI_LED_TIE_GROOVE_D     = 1.0    # zip-tie groove depth (Z, into top face)
HMI_LED_TIE_X            = 60.0   # zip-tie groove X offset from center

# === Display Tilt Lock V1.0 (Part M10-P06)  -- 2 parts: Base + Arm ===
# Two-plate friction-tilt assembly between Cross Beam and Touchscreen Frame.
# BASE bolts to beam FRONT face; ARM bolts to frame TOP TAB; the two pivot
# around a horizontal X-axis hinge with a single M5 lock thumb screw whose
# travel is constrained by an arc slot.
HMI_TILT_PLATE_W        = 180.0   # both plates share same X
HMI_TILT_PLATE_H        = 70.0    # both plates share same Z
HMI_TILT_PLATE_T        = 5.0     # both plates same Y thickness
HMI_TILT_BEAM_BOLT_Z    = 28.0    # M5 beam-mount holes Z (relative to center)
HMI_TILT_FRAME_BOLT_Z   = 22.0    # M5 frame-mount inserts Z
HMI_TILT_PIVOT_Z        = -25.0   # M5 pivot Z (below center)
HMI_TILT_LOCK_Z         = 0.0     # M5 lock-screw nominal Z (center)
# V1.1: TRUE arc slot centered on the pivot.  The lock bolt traverses an arc
# at constant radius from the pivot, eliminating side-loading of the screw.
HMI_TILT_SLOT_R         = 25.0    # arc center radius (pivot -> lock nominal)
HMI_TILT_SLOT_HALF_W    = 3.0     # slot perpendicular half-width (M5 + clearance)
HMI_TILT_ANGLE_HALF_DEG = 20.0    # +/- angular range from vertical-up
                                    # (40 deg total tilt range)
HMI_TILT_CORNER_R       = 3.0     # plate corner fillet

# === Rear Cable Cover V1.0 (Part M10-P07) ===
# Cosmetic strip that adheres to the beam REAR face, covering the cable
# channel and hiding the HDMI / USB-C / fan-power wire runs.
# Mounting: 3M VHB foam tape on the -Y face (beam-side).  Simple, removable,
# does not require any features on the beam (which is frozen at V1.2 RC1).
HMI_RCC_LEN          = 170.0   # X length (just inside beam X)
HMI_RCC_H            = 20.0    # Z height (wider than 8 mm channel for coverage)
HMI_RCC_T            = 3.0     # Y thickness
HMI_RCC_CORNER_R     = 4.0     # corner fillet (visible from rear)
HMI_RCC_CHAMFER      = 0.6     # bevel on visible edges

# === Cable Clamp V1.0 (Part M10-P08) ===
# Saddle plate that bolts to a 2020 mast slot with one M5 T-nut, holding a
# cable bundle against the mast face via 4 corner zip-tie holes.
HMI_CABLE_CLAMP_W       = 30.0    # plate X (along mast face)
HMI_CABLE_CLAMP_H       = 30.0    # plate Z (vertical)
HMI_CABLE_CLAMP_T       = 8.0     # plate thickness (Y, away from mast)
HMI_CABLE_CLAMP_TIE_D   = 3.0     # zip-tie pass-through hole diameter
HMI_CABLE_CLAMP_TIE_X   = 10.0    # zip-tie hole X offset from center
HMI_CABLE_CLAMP_TIE_Z   = 10.0    # zip-tie hole Z offset from center
HMI_CABLE_CLAMP_CORNER_R = 3.0    # plate corner fillet

# === Pi Fan Cover V1.0 (Part M10-P04) ===
# Flat plate hanging below the Pi 4 (opposite side from Pi Carrier).
# Carries a 30 x 30 x 10 mm 5V fan that blows air toward Pi components.
# Mounts via M2.5 x 25 mm screws stacked through Cover + brass standoff +
# Pi PCB + Pi Carrier insert (replaces the M2.5 x 6 mm screw from Pi Carrier).
HMI_PI_FAN_COVER_W      = 80.0     # plate X (inside Pi 88)
HMI_PI_FAN_COVER_D      = 60.0     # plate Y (matches Pi 58 + margin)
HMI_PI_FAN_COVER_T      = 3.0      # plate thickness
HMI_PI_FAN_OPENING_D    = 24.0     # round air intake (better airflow than 22)
HMI_PI_FAN_BODY_W       = 30.0     # standard 30 x 30 x 10 mm fan
HMI_PI_FAN_BODY_H       = 10.0
HMI_PI_FAN_MOUNT_PCD    = 24.0     # standard 30 mm fan screw spacing
HMI_PI_FAN_M3_CLEAR_D   = 3.7      # M3 clearance (bumped from 3.5 for fan PCD tolerance)
HMI_PI_FAN_STANDOFF_H   = 11.0     # user-supplied M2.5 brass standoff height
                                    # (Pi PCB to Fan Cover; clears 10 mm fan)
HMI_PI_FAN_VOLTAGE      = 5.0      # supplied from Pi GPIO header
HMI_PI_FAN_AIRFLOW      = "TOWARD_PI"  # arrow on fan should point at Pi PCB
HMI_PI_FAN_RIB_W        = 2.0      # stiffening rib width (perpendicular)
HMI_PI_FAN_RIB_H        = 1.5      # stiffening rib height (above top face)
# V1.2 -- slotted grille (replaces single round D24 intake)
HMI_PI_FAN_GRILLE_SLOTS    = 5     # number of parallel slots
HMI_PI_FAN_GRILLE_SLOT_W   = 3.5   # slot width (X)
HMI_PI_FAN_GRILLE_SLOT_H   = 22.0  # slot length (Y)
HMI_PI_FAN_GRILLE_WALL     = 1.6   # wall between slots (>= 4 perimeters at 0.4 mm)
# V1.2 -- additional features
HMI_PI_FAN_CORNER_R        = 3.0   # plate corner fillet radius
HMI_PI_FAN_CABLE_NOTCH_W   = 4.0   # cable exit notch width (X)
HMI_PI_FAN_CABLE_NOTCH_L   = 8.0   # cable exit notch length (X, away from fan)
HMI_PI_FAN_CABLE_NOTCH_D   = 2.0   # cable exit notch depth (Z, into plate top)
HMI_PI_HEATSINK_H_NOMINAL  = 6.0   # typical low-profile Pi 4 heatsink (set to
                                    # 8 for tall heatsinks or 0 for bare PCB)
# V1.3 -- M3 fan screw counterbore (heads flush on bottom face, away from wires)
HMI_PI_FAN_M3_CB_D         = 6.0   # M3 pan-head counterbore diameter
HMI_PI_FAN_M3_CB_H         = 1.5   # counterbore depth (into bottom face)
# V1.3 -- orientation-tolerant cable channels (replaces single corner notch)
HMI_PI_FAN_CABLE_CH_W      = 4.0   # channel width (Y dimension if X-aligned)
HMI_PI_FAN_CABLE_CH_L      = 6.0   # channel length from fan body edge
HMI_PI_FAN_CABLE_CH_D      = 1.5   # depth into plate top

# === Pi Carrier V1.0 (Part M10-P03) ===
# Adapter plate between beam (58 x 28 PCD inserts) and Pi 4 (58 x 49 PCD).
# Hangs from beam bottom face via M5 socket-head bolts going UP into beam
# inserts.  Pi 4 mounts BELOW plate via M2.5 standoffs into self-tap pilots.
HMI_PI_CARRIER_W       = 90.0              # X (along beam direction)
HMI_PI_CARRIER_D       = 60.0              # Y (front-back of machine)
HMI_PI_CARRIER_T       = 8.0               # plate thickness
HMI_PI4_PCD_X          = 58.0              # Pi 4 mount holes, X spread
HMI_PI4_PCD_Y          = 49.0              # Pi 4 mount holes, Y spread
HMI_M2_5_PILOT_D       = 2.0               # M2.5 self-tap pilot hole
HMI_M2_5_PILOT_H       = 6.0
HMI_PI_CABLE_NOTCH_W   = 14.0              # cable cutout, X width
HMI_PI_CABLE_NOTCH_D   = 6.0               # cable cutout, Y depth

# === Boolean / overcut helpers (FDM print engineering convention) ===
# Small offsets used in cuts to avoid coincident faces from Boolean ops.
# Centralized so they read as engineering intent, not magic numbers.
HMI_BOOLEAN_OVERCUT    = 0.1               # extend cut volume past target face
HMI_CUT_EXTRA          = 2.0               # extra length on through-cuts
HMI_CUT_START_OFFSET   = 0.05              # start cut just below target face

# ============================================================
# BOUGHT-PARTS DIMENSIONS (from BOM V12 -- physical inventory)
# Source of truth: 04_PURCHASING/BOM_V11/CSM_V3_BOM_V11.html
# ============================================================

# --- Drive shaft + bearings ---
SHAFT_D                = 12.00   # FEYRINX 12mm h8 (B08HX2LG53)
SHAFT_LENGTH           = 300.00  # actually-purchased shaft length
BEARING_6001_OD        = 28.00   # 6001-2RS (eBay 10pk)
BEARING_6001_ID        = 12.00
BEARING_6001_W         =  8.00
BEARING_51101_OD       = 26.00   # 51101 thrust bearings (B0G25X5L23)
BEARING_51101_ID       = 12.00
BEARING_51101_W        =  9.00
BEARING_608_OD         = 22.00   # 608-2RS skate (B0FH6QH8VQ)
BEARING_608_ID         =  8.00
BEARING_608_W          =  7.00
SHAFT_COLLAR_D         = 12.00   # 12mm clamping collars (B0DMMB1FHF)

# --- DRIVE MOTOR: NEMA 23 + 5:1 PLANETARY GEARBOX (23HS22-2804S-HG5) ---
# Source: StepperOnline direct  --  $95
# Bipolar 2.8 A holding ~2.8 N.m before gearbox, ~14 N.m at gearbox output
NEMA23_BODY_W          = 57.00     # NEMA 23 frame, 57x57 square
NEMA23_BODY_L          = 56.00     # 23HS22 = 56 mm body length
NEMA23_SHAFT_D         =  8.00     # input shaft (into gearbox, but motor side has shaft)
NEMA23_MOUNT_PCD_SQ    = 47.14     # 4x M5 square hole pattern (centre to centre)
NEMA23_MOUNT_HOLE_D    =  5.50     # M5 clearance
NEMA23_BOSS_D          = 38.10     # round register boss
NEMA23_BOSS_H          =  1.60
NEMA23_CURRENT_A       =  2.80
NEMA23_HOLDING_NM      =  2.80
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

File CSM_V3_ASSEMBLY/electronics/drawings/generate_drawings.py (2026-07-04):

# -*- coding: utf-8 -*-
"""
CSM V3 -- Wood Base Electrical Mounting Drawings Generator
============================================================
Produces engineering drawings for drilling the wood base electrical
mounts. Every dimension a machinist needs to drill the holes is shown.

Outputs:
  wood_base_top.png/.pdf       -- top view with full dimensioning
  drilling_guide.png/.pdf      -- pure drilling template with numbered
                                   holes and coordinate table
  operator_panel.png/.pdf      -- front operator panel detail
  components_card.png/.pdf     -- product reference card with ASINs

Run:
  "C:/Program Files/FreeCAD 1.1/bin/python.exe" generate_drawings.py
"""

import os, sys
import matplotlib.pyplot as plt
import matplotlib.patches as mpatches
from matplotlib.patches import Rectangle, Circle, Polygon, FancyBboxPatch
from matplotlib.lines import Line2D
from matplotlib.backends.backend_pdf import PdfPages
import numpy as np

# FreeCAD Part for STEP export (only available when run via FreeCAD's Python)
try:
    import FreeCAD
    import Part
    HAS_FREECAD = True
except ImportError:
    HAS_FREECAD = False
    print("WARNING: FreeCAD not available; STEP export will be skipped.")

# machine_datums for STEP geometry
sys.path.insert(0, r"C:\3D-Project\00_PROJECT_OVERVIEW")
try:
    import machine_datums as MD
except ImportError:
    MD = None
    print("WARNING: machine_datums not importable; STEP export will be skipped.")

# ============================================================
# WOOD BASE + INFRASTRUCTURE (from machine_datums.py)
# ============================================================
WB_W, WB_D, WB_T = 500, 400, 18
HOLE_D = 100
UP_X = [+150, -150]
UP_Y = [+120, -120]
UP_W = 20
MOTOR_X, MOTOR_Y = 85, -47

OUTDIR = os.path.dirname(os.path.abspath(__file__))

# Frame parts have their drawings in their own folders (not lumped here)
_REPO_ROOT = os.path.dirname(os.path.dirname(os.path.dirname(OUTDIR)))
FRAME_DIRS = {
    'wood_base':       os.path.join(_REPO_ROOT, 'CSM_V3_ASSEMBLY', 'frame', 'wood_base'),
    'wood_upper_deck': os.path.join(_REPO_ROOT, 'CSM_V3_ASSEMBLY', 'frame', 'wood_upper_deck'),
    'mount_plate':     os.path.join(_REPO_ROOT, 'CSM_V3_ASSEMBLY', 'frame', 'mount_plate_6061'),
}

# ============================================================
# HARDWARE SPECS PER COMPONENT
# 'bolt': thread, length (mm), head, washer, nut, hardware notes
# All bolts go THROUGH the 18 mm wood base with washer + nut underneath.
# Drill diameter = clearance for the bolt thread.
# ============================================================
HW_PSU      = dict(bolt='M4 × 30', drill='Ø4.5',
                   hardware='M4 bolt 30 mm + washer top + M4 washer bottom + M4 nut',
                   notes='Pan-head bolt; rubber washer optional under head')
HW_MOTOR    = dict(bolt='M5 × 35', drill='Ø5.5',
                   hardware='M5 bolt 35 mm + washer top + M5 lock washer + M5 nut',
                   notes='Lock washer required — motor vibrates')
HW_TB6600   = dict(bolt='M3 × 25', drill='Ø3.5',
                   hardware='M3 bolt 25 mm + washer top + M3 washer bottom + M3 nut',
                   notes='Through TB6600 flange tabs (4 mm thick)')
HW_MEGA     = dict(bolt='M3 × 30', drill='Ø3.2',
                   hardware='M3 bolt 30 mm + nylon standoff 10 mm + M3 washer + M3 nut',
                   notes='Standoff between Mega PCB and wood for airflow')
HW_BUCK     = dict(bolt='M3 × 22', drill='Ø3.2',
                   hardware='M3 bolt 22 mm + nylon standoff 5 mm + M3 washer + M3 nut',
                   notes='OR substitute 3M VHB pad — no holes needed')
HW_TERMINAL = dict(bolt='M3 × 22', drill='Ø3.2',
                   hardware='M3 bolt 22 mm + washer top + M3 washer bottom + M3 nut',
                   notes='OR DIN-rail clip to wood base')
HW_TAKEDOWN = dict(bolt='—', drill='Ø100',
                   hardware='Through-hole only (hole saw or jigsaw)',
                   notes='Sock fabric tube descends through this')

# ============================================================
# ALL COMPONENT POSITIONS + MOUNTING HOLES (single source of truth)
# ============================================================
COMPONENTS = {
    'PSU': dict(
        label='PSU Mean Well S-250-24',
        cx=-195, cy=0, w=110, d=199,
        color='#9aa1a8',
        hw=HW_PSU,
        holes=[(-47, -90, 4.5, 'M4'), (+47, -90, 4.5, 'M4'),
               (-47, +90, 4.5, 'M4'), (+47, +90, 4.5, 'M4')],
    ),
    'MOTOR': dict(
        label='NEMA 23 + HG5 gearbox',
        cx=85, cy=-47, w=57, d=57,
        color='#7a7e85',
        hw=HW_MOTOR,
        holes=[(round(47.14/2*np.cos(np.radians(a)), 2),
                round(47.14/2*np.sin(np.radians(a)), 2), 5.5, 'M5')
               for a in (45, 135, 225, 315)],
    ),
    'TB6600': dict(
        label='TB6600 stepper driver',
        cx=200, cy=-47, w=96, d=56,
        color='#c43838',
        hw=HW_TB6600,
        holes=[(-42, 0, 3.5, 'M3'), (+42, 0, 3.5, 'M3')],
    ),
    'MEGA': dict(
        label='Arduino Mega 2560',
        # cx 200 -> 195 (2026-06-28): right edge of board was at +251,
        # overhanging the 500 mm wood base by 1 mm.  Also, the right
        # mounting holes at X=247 sat only 1.4 mm from the sheet edge,
        # below SendCutSend minimum of 3.61 mm (.142") for 12 mm plywood.
        cx=195, cy=75, w=102, d=54,
        color='#1f4ea8',
        hw=HW_MEGA,
        holes=[(-47, -23, 3.2, 'M3'), (+47, -23, 3.2, 'M3'),
               (-47, +23, 3.2, 'M3'), (+47, +23, 3.2, 'M3')],
    ),
    'BUCK1': dict(
        label='LM2596 buck #1 (Mega+servo)',
        cx=-50, cy=160, w=43, d=21,
        color='#0f6b34',
        hw=HW_BUCK,
        holes=[(-18, -7, 3.2, 'M3'), (+18, +7, 3.2, 'M3')],
    ),
    'BUCK2': dict(
        label='LM2596 buck #2 (Pi)',
        cx=+50, cy=160, w=43, d=21,
        color='#0f6b34',
        hw=HW_BUCK,
        holes=[(-18, -7, 3.2, 'M3'), (+18, +7, 3.2, 'M3')],
    ),
    'TERMINAL': dict(
        label='24V distribution block',
        cx=0, cy=180, w=50, d=20,
        color='#e6dc4a',
        hw=HW_TERMINAL,
        holes=[(-22, 0, 3.2, 'M3'), (+22, 0, 3.2, 'M3')],
    ),
}
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

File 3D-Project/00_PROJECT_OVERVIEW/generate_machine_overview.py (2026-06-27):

# -*- coding: utf-8 -*-
"""
CSM V3 — Complete Machine Engineering Illustration
====================================================
Isometric cover-page drawing showing the entire 14-module machine
with correct proportions from machine_datums.py.

Output:
  CSM_V3_MACHINE_OVERVIEW.png  (high-DPI cover image)
  CSM_V3_MACHINE_OVERVIEW.pdf  (vector for print)

Run:
  "C:/Program Files/FreeCAD 1.1/bin/python.exe" generate_machine_overview.py
"""
import os
import numpy as np
import matplotlib.pyplot as plt
from mpl_toolkits.mplot3d.art3d import Poly3DCollection, Line3DCollection
import machine_datums as MD

OUTDIR = os.path.dirname(os.path.abspath(__file__))

# Colors (engineering illustration palette)
WOOD       = '#c8a878'
WOOD_DARK  = '#8c6a3f'
ALU        = '#c8ccd2'
ALU_DARK   = '#6a6e74'
STEEL      = '#888c92'
PETG_BLUE  = '#4a6a9a'
PETG_DARK  = '#2a3a5a'
CYL_GRAY   = '#a8a8b0'
CYL_DARK   = '#4a4a52'
MOTOR_DK   = '#3a3a40'
BELT_BK    = '#1a1a1a'
HOOK_LAV   = '#9990c0'
SCREEN_BK  = '#1a1a1a'
SCREEN_PX  = '#2a4a8a'
PSU_GRAY   = '#909296'
PCB_BLUE   = '#1f4ea8'
PCB_GREEN  = '#0c6e3a'
RED        = '#c43838'
YARN_COLORS = ['#c44', '#4c4', '#44c', '#cc4', '#c4c', '#4cc']

# ============================================================
# Helpers — draw 3D primitives
# ============================================================
def cylinder_mesh(cx, cy, z0, r, h, n_theta=48):
    th = np.linspace(0, 2*np.pi, n_theta + 1)
    x_bot = cx + r * np.cos(th); y_bot = cy + r * np.sin(th); z_bot = np.full_like(th, z0)
    x_top = x_bot; y_top = y_bot; z_top = np.full_like(th, z0 + h)
    return x_bot, y_bot, z_bot, x_top, y_top, z_top

def draw_cylinder(ax, cx, cy, z0, r, h, face_color, edge_color='k', n=48,
                  alpha=1.0, lw=0.5):
    th = np.linspace(0, 2*np.pi, n + 1)
    # Side surface
    x = cx + r * np.cos(th); y = cy + r * np.sin(th)
    verts_side = []
    for i in range(n):
        verts_side.append([
            (x[i], y[i], z0), (x[i+1], y[i+1], z0),
            (x[i+1], y[i+1], z0 + h), (x[i], y[i], z0 + h)
        ])
    side = Poly3DCollection(verts_side, facecolors=face_color,
                            edgecolors=edge_color, linewidths=lw, alpha=alpha)
    ax.add_collection3d(side)
    # Top and bottom rings
    top = list(zip(x, y, np.full_like(x, z0 + h)))
    bot = list(zip(x, y, np.full_like(x, z0)))
    ring_top = Poly3DCollection([top], facecolors=face_color,
                                 edgecolors=edge_color, linewidths=lw, alpha=alpha)
    ring_bot = Poly3DCollection([bot], facecolors=face_color,
                                 edgecolors=edge_color, linewidths=lw, alpha=alpha)
    ax.add_collection3d(ring_top)
    ax.add_collection3d(ring_bot)

def draw_hollow_cyl(ax, cx, cy, z0, r_out, r_in, h, color, edge='k', alpha=1.0, n=48):
    draw_cylinder(ax, cx, cy, z0, r_out, h, color, edge, n=n, alpha=alpha)
    # Inner hole shadow (just visible as a darker ring on top)
    th = np.linspace(0, 2*np.pi, n + 1)
    x = cx + r_in * np.cos(th); y = cy + r_in * np.sin(th)
    inner_top = list(zip(x, y, np.full_like(x, z0 + h)))
    ax.add_collection3d(Poly3DCollection([inner_top], facecolors='#222',
                                          edgecolors=edge, linewidths=0.4, alpha=alpha))
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

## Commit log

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2026-05-17 Cylinder V3.0: shallower slots, solid bottom ring, two test wedges
    Engineering changes calibrated against the reference STL "Cylinder 72 Slots":
    - SLOT_DEPTH: 3.40 -> 3.00 mm
    Reference STL has 2.55mm slot depth. 3.00mm gives 0.45mm safety margin
    while staying close to the empirical "known good" value. Avoids the
    over-cautious 3.40mm depth that risked excessive fin flex in PETG.
    - SPRING_GROOVE_DEPTH: 1.7 -> 1.3 mm
    Coupled to SLOT_DEPTH: groove >= slot - 1.80mm for spring reach.
    With slot=3.0 and groove=1.3, preload = 0.10mm (creep margin).
    Spring protrudes 1.49mm past OD (clearly visible coil).
    - Slots now stop at Z=BOTTOM_THICK (Z=12mm), not Z=0
    The bottom mounting ring is n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
    [CSM_V3_Cylinder_V3_0_FULL.stl, CSM_V3_Cylinder_V3_0_WEDGE_A_WIDTH.stl, CSM_V3_Cylinder_V3_0_WEDGE_B_DEPTH.stl]
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2026-05-17 Add Cassette Base V1.0 (was missing piece blocking 3 other components)
    Designed by ChatGPT (parameter table + macro skeleton) and verified +
    corrected against all locked interfaces. ONE structural fix required
    from the original ChatGPT proposal:
    CRITICAL FIX: ChatGPT's flat-disc design would have placed the sinker
    ring 12mm BELOW its required Z=75 position on the cylinder. Added a
    central 12mm raised step (riser) to bring the sinker register up to
    the correct height. Single stepped part, no extra components needed.
    VERIFIED INTERFACES (all match locked specs):
    - Cam Ring V6.5: 6x M5 PCD 155 + 6x D4 pins PCD 145 (alternating)
    - Sinker Ring V1.2.1: D135 register pocket, 1mm tall locating li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
    [CSM_V3_CassetteBase_V1_0_FULL.stl]
2026-05-18 Cassette Base V1.0 -> V1.1: annular pedestal + fixed register + named Z datums
    Three structural changes after engineering review:
    1. ANNULAR SINKER PEDESTAL (was: solid riser with inherited inner edge)
    SINKER_PEDESTAL_OD: 145 -> 150
    SINKER_PEDESTAL_ID: implicit-117 -> explicit-128
    The pedestal is now decoupled from the cylinder pass-through. Creates a
    visible "shelf" between cylinder (D117) and pedestal inner edge (D128).
    Benefits: less PETG warp, better airflow, easier yarn access, cleaner
    architecture for the future ribber mount.
    2. RIBBER MOUNT PCD: 128 -> 140
    Reviewer proposed PEDESTAL_ID=128 AND ribber PCD=128, which would have
    put M4 ribber holes exactly at th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
    [CSM_V3_CamRing_V6_5_FULL.stl, CSM_V3_CamRing_V6_5_TESTSLICE.stl, CSM_V3_CassetteBase_V1_0_FULL.stl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]
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2026-05-18 Retainer Ring V1.0 + INTERFACE_CONTROL.md R2 (lock Interface 7)
    PART: Cassette Head -- Retainer Ring V1.0
    LOCATION: 02_CASSETTE_HEAD/retainer_ring/
    DESIGNED BY: ChatGPT (proposal) + verified/corrected/translated to project style
    FUNCTION:
    Loop-control ring above the sinker ring. Prevents knit loops from rising
    too high during cam-driven needle lift. Two-diameter architecture:
    - Large D118 center bore: free cylinder rotation clearance (1.85mm/side)
    - Inward D104 lip at top: effective loop-control aperture (5.15mm inward
    from cylinder OD radius -- industrial-safe range)
    GEOMETRY:
    RR_OD = 200.0 (matches Cassette Base OD)
    RR_THICK = 8.0
    RR_CENTER_BORE_D = 118.0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
    [CSM_V3_RetainerRing_V1_0_FULL.stl]
2026-05-20 Cylinder V3.0: WEDGE_B depth sweep -> Option B (coupled depth + groove)
    WEDGE_B_SLOTS now tests slot depths 2.5..5.0mm with matched groove
    depths 0.9..3.4mm, holding spring preload constant at +0.20mm across
    all 6 slots. This isolates depth as the variable while keeping the
    spring actually engaged on every test slot (previous fixed-1.3mm
    groove only engaged for slots <= 3.1mm depth).
    build_wedge() extended to cut per-slot angular groove segments when
    slot entries carry their own groove depth (3-tuple form). WEDGE_A
    unchanged (still uses shared global groove via 2-tuple form).
    Also:
    - Fixed undefined PATH_STL_WEDGE -> PATH_STL_WEDGE_A / PATH_STL_WEDGE_B
    in the final summary print.
    -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
    [CSM_V3_Cylinder_V3_0_WEDGE_B_DEPTH.stl]
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2026-05-23 Phase 1.5 D-2: 8 failure scenarios (A1-A3 timing, B1-B2 tension, C1-C2 geom, D1-D2 capture)
    [CSM_V3_Phase15_Failures.blend]
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2026-05-24 6-poster engineering set (P1 overview, P2 drive, P3 yarn, P4 triad, P5 service, P6 failure)
    [build_posters.py]
2026-05-24 MD R3 -> R4 (belt geometry fix C=97.29mm) + adopt canonical poster V2
    [machine_datums.py]
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2026-05-27 Part B: FeederModule V1.2E (adjustable ceramic-pigtail clamp, first-print candidate)
    Replaces V1.1 printed PETG yarn-exit hole with a slot-mounted M4 jam-nut
    clamp for the ceramic pigtail B0FLJK48BB. Designed around the real
    hardware (offset ceramic eye + metal sleeve shoulder + dual jam nuts),
    not an embedded-insert abstraction.
    Tuning DOFs (motivated by D-4b yarn-sensitivity findings):
    - tangential slot translation: +/- 3 mm
    - relative stem rotation: ~+/- 20 deg via integrated ridge channel
    Other refinements during this revision pass:
    - block redesigned as vertical pillar on base (V1.2A floated in space)
    - block T 8 -> 10 mm, 2 mm base overlap for PETG layer continuity
    - sleeve sea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
    [CSM_V3_FeederModule_V1_1.stl, CSM_V3_FeederModule_V1_2E.stl]
2026-05-29 Part D: Take-Down Hook Adapter V1.0F (Phase 1 bring-up consumable)
    Multi-point hook ring that sits inside the knit fabric tube, engages the
    bottom course of stitches via 4 distributed downward hooks, and carries
    the take-down weight through a central cord eye on a 2-arm spider.
    Design rationale (D-4b derived):
    - B1 slack tolerance ~+/-2 mm before capture failure, so distributed
    hooks pull evenly around the circumference (vs single-tail J-hook)
    - central cord eye self-centers the weight (cord = virtual gimbal)
    Geometry (textile-safe, low-inertia):
    - ring OD 75 x ID 57 x 6.5 mm (drops through D100 wood-base column)
    - 4x cylindrical hooks D2.2, depth 10 mm, 1.8 mm inward barb, rounded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
    [CSM_V3_TakeDownHookAdapter_V1_0F.stl]
2026-05-29 Part I: Needle Set & Index Collar V1.0A (Phase 1 assembly aid)
    Jig for populating the V3.1 cylinder with 72 latch needles. Clips over
    the cylinder OD; inner datum hub bottoms on the top-face annulus (Z ref);
    72 segmented push pads press each needle shank down to a uniform height;
    72 index notches (one wide ref at theta=0) confirm full population before
    seating.
    Design logic:
    - datum hub rests INSIDE the slot circle (r46-54) -> no needle collision
    - open D92 center -> finger access + cylinder-bore visibility (no "lid")
    - 72 segmented pads (w3, r52-58.5) press shank only, tolerant of latch-
    tongue rotation variance; each pad bridges wall->skirt as a stiff rib
    - PAD_R_OUT 58.5 reaches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
    [CSM_V3_NeedleSetCollar_V1_0A.stl]
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2026-05-31 Part D V1.0G: fix floating eye-post cantilever (extend post to bed)
    V1.0F bug: spider eye post (D13 cylinder) started at Z=RING_T (6.5 mm)
    floating over the ring's open ID, with no support below it during FDM
    printing. Slicer would have needed support material across the ring
    interior bore.
    V1.0G fix: extend eye post from Z=0 (bed) to full height. Post is now a
    self-supporting column; spider arms become bridges with both ends
    anchored (ring inner wall + supported post). 23 mm bridge span is well
    within PETG capability.
    Verified:
    - new STL generated cleanly (16.9 MB, 20.3 g PETG vs V1.0F 19.2 g)
    - volume change +863 mm^3 = exactly the predicted column extension
    - no other geometry change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
    [CSM_V3_TakeDownHookAdapter_V1_0F.stl, CSM_V3_TakeDownHookAdapter_V1_0G.stl]
2026-05-31 Part D V1.0H: hook robustness pass (D2.2 -> D3.0, length 10 -> 8, root fillet)
    Reported failure: V1.0G hook stems broke under light handling.
    Fixes:
    - HOOK_THICKNESS 2.2 -> 3.0 mm (d^3 scaling: 2.54x stronger)
    - HOOK_DEPTH 10 -> 8 mm (linear: 1.25x stronger)
    - BASE_BLEND_R r_stem -> 2.0 (proper fillet at root)
    - HOOK_BARB_OFFSET 1.8 unchanged (stitch retention preserved)
    Practical break load: ~2 N -> ~6.5 N (~3.2x stronger).
    Mass change: 20.3 -> 20.4 g PETG (negligible).
    In-use: D3 hooks engage 1 of 18 stitches each; fabric stretch handles.
    V1.0G archived to _archive/v1_0G_locked_2026-05-27/
    ICD + Phase 1 Guide refs updated V1.0G -> V1.0H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
    [CSM_V3_TakeDownHookAdapter_V1_0G.stl]
2026-05-31 Part D V2.0: metal hooks in printed carrier (PETG cantilevers abandoned)
    User report: hook stems break by touch, even after V1.0H robustness pass
    (D3.0 stems, 8 mm length, 2 mm root fillet, 3.2x stronger than V1.0F).
    Root cause we cannot fix in PETG:
    - Thin vertical cantilever (any D <= 3 mm) prints with horizontal
    layer lines crossing the bending stress plane
    - Layer adhesion is 30-50% of bulk PETG and unpredictable batch-to-batch
    - Even 3x geometric strength cannot compensate -- the FDM weakness IS
    in the print direction itself
    - Industry doesn't do this -- real circular sock machines use metal
    take-down hooks for exactly this reason
    V2.0 architectural change:
    - Stop printi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
    [CSM_V3_TakeDownHookAdapter_V2_0.stl]
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2026-06-05 Drawings V1.1: add full dimensions + drill sizes + bolt specs
    Per user feedback "no width/height info, asking drill holes but missing
    dimensions/bolts". Major upgrade to the engineering drawings:
    Sheet 1 (wood_base_top) NOW SHOWS:
    - Overall 500x400 dimensions (was missing edge-to-edge)
    - Half-width dimensions 250/250 X and 200/200 Y to show centering
    - Upright pitch 300 X and 240 Y in blue
    - Every component center coordinate labeled (X, Y) on the box
    - Component sizes (W x D) shown inside each box
    - Component center X positions from datum in blue dim lines
    - Component center Y positions from datum in blue dim lines
    - Hole-to-hole pitches inside each component (PSU 94x180, Mega 94x46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
    [generate_drawings.py]
2026-06-06 Hardware order sheet V1.0 (A4 printable, checkboxes)
    Single-page printable PDF designed to take to the hardware store.
    Layout: A4 portrait, 6 numbered sections, checkbox + qty + size +
    use + notes per row.
    1. BOLTS (blue band)
    [ ] 4x M5 x 35 mm NEMA 23 motor flange (use w/ lock washer + threadlock)
    [ ] 4x M4 x 30 mm PSU chassis
    [ ] 4x M3 x 30 mm Arduino Mega (with standoffs)
    [ ] 2x M3 x 25 mm TB6600 stepper driver flange
    [ ] 6x M3 x 22 mm Bucks (x4) + Terminal (x2)
    Subtotal: 20 bolts (16 if using VHB on Bucks)
    2. WASHERS
    [ ] 8x M5 flat, [ ] 4x M5 lock (MANDATORY - motor vibrates),
    [ ] 8x M4 flat, [ ] 24x M3 flat
    3. NUTS
    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
    [generate_drawings.py]
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2026-06-27 Add STEP files (3D solid models) for the 3 CNC frame parts
    DXF files are 2D-only (outline + holes). Thickness must be specified in
    the shop's order form. The shop reported confusion: 'where is 18 mm in
    the file?' STEP files solve this by embedding thickness in 3D geometry.
    NEW FILES:
    frame/wood_base/CSM_V3_WoodBase_V1_1_500x400x18.step
    frame/wood_upper_deck/CSM_V3_WoodUpperDeck_V1_0_320x260x18.step
    frame/mount_plate_6061/CSM_V3_MountPlate6061_V1_1_250x250x6.step
    Each STEP file contains:
    - Full 3D solid with correct thickness
    - All holes drilled all the way through
    - Can be opened in any CAD viewer (FreeCAD, Fusion, OnShape, etc.)
    - Industry standard for CNC quoting
    Generator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
    [CSM_V3_MountPlate6061_V1_1_250x250x6.dxf, CSM_V3_MountPlate6061_V1_1_250x250x6.step, CSM_V3_WoodBase_V1_1_500x400x18.dxf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]
2026-06-27 Aluminum master-datum plate: 6.0 -> 6.3 mm (1/4 inch supplier stock)
    User ordering aluminum plate; supplier offers 4.7 mm or 6.3 mm.
    6.3 mm picked (closer to designed 6.0 + 2.4x stiffer than 4.7).
    Changes:
    machine_datums.py:
    ALU_PLATE_T: 6.0 -> 6.3
    ALU_PLATE_BOTTOM_Z: 224 -> 223.7
    ALU_PLATE_TOP_Z: 230 -> 230 (UNCHANGED, master datum locked)
    ALU_PLATE_PURCHASED_T: 6.00 -> 6.30
    The master datum (top surface = Z=230) is locked by ICD invariant B3.
    Only the bottom shifts down 0.3 mm. Wood deck and uprights unchanged
    - the 0.3 mm tolerance is absorbed at the wood-aluminum interface.
    generate_drawings.py:
    ALU_T: 6 -> 6.3
    Title block and DXF text labe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
    [CSM_V3_MountPlate6061_V1_1_250x250x6_3.dxf, CSM_V3_MountPlate6061_V1_1_250x250x6_3.step, CSM_V3_WoodBase_V1_1_500x400x18.step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]
2026-06-27 Wood 18 -> 12 mm + uprights 188 -> 200 mm (user ordered 12 mm Baltic Birch)
    User ordered both wood pieces at 12 mm Baltic Birch:
    Wood base: 500 x 400 x 12 mm
    Wood upper deck: 320 x 260 x 12 mm
    Stack rebalanced to keep master datum at Z=230 (ICD invariant B3):
    Z stack (floor -> master datum):
    0 -> wood base bottom
    12 -> wood base top / upright bottom (was 18)
    211.7 -> upright top / upper deck bottom (was 206)
    223.7 -> upper deck top / aluminum plate bottom (was 224)
    230.0 -> aluminum plate TOP = MASTER DATUM (unchanged)
    Practical: order 2020 uprights at 200 mm (cut tolerance absorbs the
    0.3 mm needed for CAD-exact 199.7).
    machine_datums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
    [CSM_V3_MountPlate6061_V1_1_250x250x6_3.step, CSM_V3_WoodBase_V1_1_500x400x12.dxf, CSM_V3_WoodBase_V1_1_500x400x12.step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]
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2026-06-28 HMI Mast Base Socket V1.1 (engineering review changes)
    User engineering review of V1.0 recommended 3 changes. V1.1 implements:
    1. Socket engagement 35 -> 50 mm (better twist resistance)
    - Mast-to-grip aspect ratio improved 11.4:1 -> 8:1
    - Lateral T-bolt Z positions widened: 10/25 -> 12/38 mm
    - Cable channel + expansion pockets stretched to match
    2. Foot-to-socket junction fillet attempted (3 mm radius)
    - Wrapped in try/except per established pattern
    - OCC throws IndexError on heavily-boolean shapes (known risk)
    - V1.1 falls back to unfilleted; geometry remains valid
    - Console reports "fillet failed (IndexError): skipped"
    - V1.2 candidate: manual sphere/cylinder blen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
    [CSM_V3_MastBaseSocket_V1_0.step, CSM_V3_MastBaseSocket_V1_0.stl, CSM_V3_MastBaseSocket_V1_1.step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]
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2026-06-28 HMI Module 10 -- Mast Base Socket V1.2 + Cross Beam V1.1
    Both parts revised per engineering review of V1.1 / V1.0.
    V1.1 / V1.0 files retained for history; new versions are primary.
    == Mast Base Socket V1.2 ==
    1. Pocket inner fillets R1.5 (printability + insertion + stress)
    2. Gussets enlarged 18x22 -> 25x30 (stiffness)
    3. Foot thickness 8 -> 10 mm (countersink margin, less flex)
    4. Two anti-creep ribs (3 x 6) on foot top, socket -> outer bolts
    5. Foot bolt recess: CSK -> counterbore 9.5 x 5.5 (matches socket-head)
    6. Heat-set insert pitch 10 -> 20 mm (standard accessory patterns)
    7. cut_cylinder() helper, loops simplified
    Mass ~95 g each (was 82 g V1.1). Print 2.
    == Cross Beam V1.1 ==
    1. B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
    [CSM_V3_CrossBeam_V1_1.step, CSM_V3_CrossBeam_V1_1.stl, CSM_V3_MastBaseSocket_V1_2.step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]
2026-06-28 HMI Module 10 -- Mast Socket V1.3 + Cross Beam V1.2 (FREEZE candidates)
    Engineering-review freeze pass. Both parts now wall-thickness verified.
    The verification block surfaced THREE real bugs hiding in V1.0/V1.1/V1.2:
    == Bugs found by wall-check (and fixed) ==
    1. Socket: M5 heat-set insert pocket (8.5 mm) exceeded front wall (6.6 mm)
    -- inserts would have poked into the 2020 bore interior, blocking
    extrusion seating. Has been present since V1.0.
    2. Socket: foot bolt counterbore (Ø9.5) tangent to socket OD on Y axis.
    3. Beam: mast pocket (20.8 sq) overhung beam end by 0.4 mm -- closed
    end cap was not actually closed.
    4. Beam: PI_PCD_Y=49 set in V1.1 does not fit in a 40 mm-wide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
    [CSM_V3_CrossBeam_V1_2.step, CSM_V3_CrossBeam_V1_2.stl, CSM_V3_MastBaseSocket_V1_3.step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]
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2026-06-28 HMI Module 10 RC1 -- standard CSM V3 macro metadata header
    Last polish before locking Module 10 forever.
    Both macros now begin with a uniform metadata block:
    PART_NUMBER, PART_NAME, VERSION, STATUS, PART_ID,
    PRINT_QTY, PRINT_MATERIAL, PRINT_INFILL, PRINT_LAYER, PRINT_WALLS
    Filenames, FreeCAD document name, and Part::Feature label are now all
    derived from PART_ID -- no filename drift on future revisions. Banner
    output is generated from the metadata.
    CSM V3 Part M10-P01 Mast Base Socket V1.3 RC1 [FROZEN]
    CSM V3 Part M10-P02 Cross Beam V1.2 RC1 [FROZEN]
    No geometry change (verified -- identical volumes, centers of mass,
    STL/STEP outputs).
    This convention will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
    [CSM_V3_CrossBeam_V1_2.step, CSM_V3_MastBaseSocket_V1_3.step]
2026-06-28 HMI Module 10 -- Pi Carrier V1.0 (Part M10-P03, DRAFT)
    Adapter plate hanging below Cross Beam V1.2, carrying Raspberry Pi 4.
    First downstream part designed against the frozen Module 10 interfaces.
    * Plate: 90 x 60 x 8 mm PETG, ~52 g, print flat
    * TOP face mates to beam BOTTOM face (no clearance)
    * 4x M5 through-hole + bottom counterbore at PCD 58 x 28
    (matches HMI_PI_MOUNT_PCD_*; bolts go UP into beam inserts)
    * 4x M2.5 self-tap pilots at PCD 58 x 49 on BOTTOM face
    (Pi 4 native footprint; standoffs thread in for Pi mount)
    * 14 x 6 cable notch on -Y edge for USB/power strain relief
    * Pi SD card slot points UP into beam service opening
    WALL-CHECK ALL OK -- 6 ligaments verified, min 4.5 m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
    [CSM_V3_PiCarrier_V1_0.step, CSM_V3_PiCarrier_V1_0.stl]
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2026-06-28 HMI Module 10 -- Pi Carrier V1.0 promoted to RC1 (housekeeping pass)
    Engineering-review polish only. No geometry change verified by
    identical volume (40656 mm^3) and center of mass (0, +0.45, +4.03).
    * STATUS "DRAFT" -> "RC1" (banner now reads [RC1])
    * Removed unused CUT_START_OFF constant (not referenced in this macro)
    * Renamed two existing wall checks to make engineering intent explicit:
    "Plate edge to beam bolt CB" -> "Counterbore clearance to edge"
    * Added new wall check: "Material above M2.5 pilot (Z)" = 2.00 mm
    (min 2.0). Guards against future edits to HMI_M2_5_PILOT_H that
    could push the pilot through the top of the plate.
    * Clarified assembly step 2 -- explicit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
    [CSM_V3_PiCarrier_V1_0.step]
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2026-06-28 HMI Module 10 -- Touchscreen Frame V1.0 -> V1.1 (universal mounting)
    Replace V1.0 elongated slots with V1.1 corner WINDOWS. ELECROW
    RC070S back-panel PCD is unknown until first install, so the frame
    now accommodates ANY 4-corner mounting pattern within a generous
    adjustment range -- no measurement needed before printing.
    * Screen mount: 4x corner windows (30 W x 30 H mm) instead of
    elongated slots (20 W x 10 H mm).
    * Nominal PCD updated: 130 x 75 -> 58 x 49 (Pi 4 native pattern,
    most likely per ELECROW kit hardware).
    * PCD adjustment range:
    X 28-88 mm (covers Pi 4 58, VESA-75 75)
    Y 19-79 mm (covers Pi 4 49, VESA-75 75)
    * Assembly uses M2.5 screw + ~10 mm OD fender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
    [CSM_V3_TouchscreenFrame_V1_1.step, CSM_V3_TouchscreenFrame_V1_1.stl]
2026-06-28 HMI Module 10 -- Touchscreen Frame V1.1 -> V1.2 (real ELECROW dimensions)
    Updated from official ELECROW RC070S engineering drawing (saved in
    folder as ELECROW_RC070S_official_drawing.pdf). Real measurements
    replace earlier assumptions.
    Corrections from drawing:
    * Panel outer: 165 x 100 -> 164.9 x 102 mm (real, not Amazon's)
    * Active area: (unspec) -> 154.21 x 85.92 mm
    * Total depth: 10 mm -> 34.73 mm (LCM + back PCB; was just LCM)
    * Mount PCD: assumed 58 x 49 (Pi 4) -> measured 79.45 x 64.4 mm
    * Power port: "USB" -> USB Type-C
    Frame V1.2 changes:
    * Nominal screen PCD updated 58 x 49 -> 80 x 64 (centers windows on
    the actual mount holes per dra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
    [CSM_V3_TouchscreenFrame_V1_2.step, CSM_V3_TouchscreenFrame_V1_2.stl]
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2026-06-28 HMI Module 10 -- Pi Fan Cover V1.0 (Part M10-P04, DRAFT)
    Active cooling for the Raspberry Pi 4 to prevent thermal throttling.
    Flat plate that hangs below the Pi (opposite the Pi Carrier) carrying
    a standard 30 x 30 x 10 mm 5 V brushless fan.
    * Plate: 80 x 60 x 3 mm PETG, ~17 g, ~30 min print
    * 4x M2.5 clearance through-holes at PCD 58 x 49 (Pi 4 native pattern,
    same as Pi Carrier's Pi-side mount)
    * 4x M3 clearance through-holes at PCD 24 x 24 (standard 30 mm fan
    mount pattern)
    * D22 round air intake at center (clears 25 mm fan blade swept area)
    * Fan sits in the 11 mm gap between Pi PCB and Cover plate
    * All 7 wall-thickness checks pass
    Mount stack:
    Pi Carrier
    | -- M2.5 c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
    [CSM_V3_PiFanCover_V1_0.step, CSM_V3_PiFanCover_V1_0.stl]
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2026-06-28 HMI Module 10 -- Pi Fan Cover V1.0 -> V1.1 RC1 (engineering review)
    Apply all four recommendations from the V1.0 review, plus the smaller
    labeling/naming polish. Now an RC1 freeze candidate.
    V1.1 changes:
    * Intake opening D22 -> D24 (more free area, lower pressure drop;
    remaining material to fan mount hole = 3.22 mm, still well above
    the 2 mm minimum).
    * 4 diagonal stiffening RIBS added on TOP face, each running from
    a Pi mount hole toward the central opening. 2 mm wide x 1.5 mm
    tall; length set so rib ends 1 mm outside the 30 x 30 fan
    footprint. Suppresses fan-induced plate resonance with almost
    zero extra material.
    * Airflow described as "fan arrow points TOWARD the Pi PCB"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
    [CSM_V3_PiFanCover_V1_0.step, CSM_V3_PiFanCover_V1_0.stl, CSM_V3_PiFanCover_V1_1.step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]
2026-06-28 HMI Module 10 -- Pi Fan Cover V1.1 -> V1.2 RC2
    Apply all five engineering refinements from V1.1 review.
    V1.2 changes:
    * SLOTTED GRILLE replaces single round D24 intake.
    5 parallel slots, 3.5 mm wide x 22 mm long, separated by 1.6 mm
    walls. Free area 385 mm^2 (vs 452 for D24) -- slightly less than
    the single hole but with finger / wire protection and (per review)
    better aerodynamics from multiple smaller openings.
    * CORNER FILLETS R3.0 on all 4 plate corners. Implemented via
    rounded_rect_face sketch + extrude (not post-boolean makeFillet);
    this guarantees the fillets without OCC topology fragility.
    * CABLE EXIT NOTCH on top face beside +X fan mount hole.
    4 x 8 x 2 mm pocket -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
    [CSM_V3_PiFanCover_V1_1.step, CSM_V3_PiFanCover_V1_1.stl, CSM_V3_PiFanCover_V1_2.step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]
2026-06-28 HMI Module 10 -- Pi Fan Cover V1.2 RC2 -> V1.3 RELEASE
    Apply all 5 V1.2 review refinements; first STATUS = RELEASE in
    the project.
    V1.3 changes:
    * CAPSULE-shape grille slots (semicircle ends) replace rectangular
    slots. New capsule_face() helper added; rounded_rect_face cannot
    produce r=w/2 capsules (degenerate edges). No sharp internal
    corners, cleaner appearance, slight aerodynamic improvement.
    * M3 fan-screw COUNTERBORES (Ø6 x 1.5 mm) on BOTTOM face. Pan-head
    screws now sit flush -- no head protrusion to snag wires.
    * ORIENTATION-TOLERANT cable channels: 2 symmetric radial slots
    (+X and -X) on top face, 4 x 6 x 1.5 mm each. Replaces V1.2's
    single +X +Y corner notch. User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
    [CSM_V3_PiFanCover_V1_2.step, CSM_V3_PiFanCover_V1_2.stl, CSM_V3_PiFanCover_V1_3.step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]
2026-06-28 Wood base DXF: move Mega cx 200 -> 195 (SendCutSend edge minimum)
    SendCutSend rejected the wood base DXF because two of the Arduino
    Mega 2560 mounting holes sat too close to the +X sheet edge:
    Hole at (247, 52), D3.2 mm: edge distance 1.40 mm
    Hole at (247, 98), D3.2 mm: edge distance 1.40 mm
    Required minimum: 3.61 mm (.142") for 12 mm Baltic Birch
    In the original layout the Mega's BODY also overhung the wood base
    edge by 1 mm (cx=200 + half-width 51 = 251, sheet half-width 250).
    Fix: cx 200 -> 195. Right edge of board now at +246 (4 mm inside the
    500 mm sheet) and right mounting holes at X=242 (6.40 mm edge
    distance, well above the 3.61 mm SendCutSend minimum).
    All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
    [CSM_V3_MountPlate6061_V1_1_250x250x6_3.step, CSM_V3_WoodBase_V1_1_500x400x12.dxf, CSM_V3_WoodBase_V1_1_500x400x12.step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]
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
